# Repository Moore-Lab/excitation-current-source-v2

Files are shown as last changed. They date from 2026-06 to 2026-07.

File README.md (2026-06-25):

# RTD Readout Board

Multi-channel 4-wire RTD readout for a LabJack T7 Pro.

Each RTD gets its own constant-current loop: a **current-regulator diode (CRD, ~220 µA)**
drives a precision **reference resistor R_ref** in series with the RTD. The RTD voltage
**V_RTD** is read on the T7's existing differential pairs; the current-sense voltage
**V_ref** is digitized on-board by **I²C ADS1115** ADCs on the T7's digital lines. Each RTD
is then computed **ratiometrically** as `R_RTD = C · (V_RTD / V_ref)`, where the per-channel
constant `C` is found by one-time **cross-calibration** against a known resistor. This makes
the result independent of the CRD's accuracy and R_ref's absolute value, and fits within the
T7's already-committed 7 analog pairs by moving V_ref onto the I²C bus.

**This build (locked, `docs/board_spec.md` §Resolved inputs):** Pt100 RTDs, T7 range ±0.1 V;
**3 channels** → 3 CRD/R_ref unit cells, **2 ADS1115** (ADDR 0x48/0x49; 4 differential V_ref
reads, 1 spare), 3 RTD 4-wire connectors. The result is **ratiometric across two ADCs**
(T7 + ADS1115), so the dominant design concern is protecting the precision-analog path
(sense + V_ref) and keeping the I²C/digital side off it.

## Where to start
- **Read this first:** `docs/USER_MANUAL.md` — one place to understand the board, see what was
  built, and check the verification evidence (ERC/DRC/SPICE) before fab.
- **Design:** `docs/board_spec.md` (electrical source of truth).
- **Working with Claude Code:** `CLAUDE.md` → `docs/SESSION_KICKOFF.md`.
- **Running multiple sessions in parallel:** `docs/PARALLEL_PLAN.md` + `docs/tasks/`.
- **Process:** `docs/DIRECTORY_MANAGEMENT.md`, `docs/BOARD_DEV_CHECKLIST.md`,
  `docs/TESTING_PLAN.md`.

## Toolchain
- **KiCad 10.0.3** — pinned. The gate scripts auto-discover `kicad-cli` on `PATH`, else at
  the standard Windows install (`C:\Program Files\KiCad\<ver>\bin\kicad-cli.exe`); override
  with `KICAD_CLI=/path/to/kicad-cli`. A KiCad **major** bump can rewrite the `.kicad_*`
  formats — bump the pin in `scripts/lib.sh` deliberately and note it in the log.
- **ngspice** — SPICE engine for Track B's harness (`sim/`).
- **Python + LabJack LJM** — acquisition library in `host/` (Track C). *Not* used by the gate
  scripts, which are POSIX `sh` (run under Git Bash on Windows or natively on Linux/macOS).

## Validation gates
The cheap, machine-checkable gates run from one entry point. It **degrades gracefully**: with
no KiCad design files yet (before the schematic/PCB land) it reports "nothing to check" and
exits 0, so every track and the integration step run it identically.

```sh
sh scripts/run_gates            # ERC + DRC -> reports/{erc,drc}/, nonzero on any error
sh scripts/run_gates --tag s007 # stamp reports as erc_s007.json / drc_s007.json
```

| Script | Does | Output |
|---|---|---|
| `scripts/run_gates` | ERC + DRC; the gate every session runs | `reports/{erc,drc}/*.json` |
| `scripts/erc` | ERC only (canonical command) | `reports/erc/erc_<tag>.json` |
| `scripts/drc` | DRC only (refills zones; never saves the board) | `reports/drc/drc_<tag>.json` |
| `scripts/export_bom` | BOM incl. **Tempco** field (R_ref stability) | `reports/bom/bom_<tag>.csv` |
| `scripts/export_netlist` | Schematic netlist for the SPICE harness | `sim/netlists/rtd-readout.net` |
| `scripts/fab_drop` | Gerbers + drill + pos + STEP + BOM | `fab/**` (gitignored) |
| `scripts/lib.sh` | Shared helpers (sourced, not run) | — |

`reports/**` is generated but **committed** (cheap, diffs well, gives the log something to
cite); regenerate it from these scripts, never hand-edit. Default tag is `latest` (overwrites
for clean diffs); pass `--tag sNNN` to keep a session-stamped copy.

### Optional: enforce gates on commit
```sh
sh scripts/install_hooks   # installs a pre-commit hook that runs scripts/run_gates
```
Opt-in (not installed automatically, so it never surprises a parallel-track worktree). It's a
no-op until the schematic/PCB exist. Remove it with `rm "$(git rev-parse --git-path hooks)/pre-commit"`.

## Cutting a fab drop
Only at a reviewed, **DRC-clean, tagged** rev — `fab/` is gitignored; capture the drop with a
git tag, never leave it in-tree (`docs/DIRECTORY_MANAGEMENT.md`).

```sh
sh scripts/run_gates && git tag rev-A     # gate, then tag the reviewed state
sh scripts/fab_drop                       # gerbers/drill/pos/step/bom -> fab/
git tag fab-rev-A                          # capture the manufacturing drop
```

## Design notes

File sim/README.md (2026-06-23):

# sim/ — SPICE verification harness (Track B)

Headless ngspice proof that the RTD-readout circuit is correct and a quantified
accuracy/noise budget, built on a **modeled** circuit before the board exists.
Implements TESTING_PLAN Part 1. Pt100, 3 channels (`docs/board_spec.md`).

## Layout

```
sim/
├── models/        shared, reused by every deck
│   ├── params.inc   design nominals (CRD, R_ref, gains, Pt100 sweep window)
│   ├── crd.inc      current-regulator diode: I_src || finite Z_dyn, scalable
│   ├── meas.inc     the two ADCs as ideal differential gain blocks (T7, ADS1115)
│   ├── knobs.inc    sweep/perturbation variables carried as node voltages
│   └── channel.inc  one unit cell (CRD + R_ref + RTD + both ADC reads)
├── netlists/      one deck per TESTING_PLAN Part-1 test (test1..test7)
└── scripts/
    ├── spice_io.py  ngspice locator, wrdata loader, report writer, constants
    └── run_all.py   single entry: run decks -> analyse -> plots + reports
```

## Run it

```bash
# from the repo root
python sim/scripts/run_all.py            # run all decks, analyse, write reports
python sim/scripts/run_all.py --no-run   # re-analyse existing data only
```

Outputs (committed): one report per test in `reports/sim/*.md` and plots in
`reports/sim/plots/`. Intermediate `reports/sim/{data,logs}/` are regenerable and
gitignored. Exit code is non-zero if any test FAILs.

## ngspice

Needs the **console/batch** build (`ngspice_con` / `ngspice -b`). The harness
auto-detects it via, in order: `$NGSPICE_BIN`, a conda env named `spice`, then
`PATH`. Provision once with conda-forge (portable, no system install):

```bash
conda create -y -n spice -c conda-forge ngspice      # ships ngspice_con.exe
```

Pinned/validated: **ngspice-41**. KiCad bundles only `ngspice.dll` (no CLI), so a
standalone batch binary is required.

## What each test proves (all PASS on the modeled circuit)

| Deck | Proves | Headline result |
|---|---|---|
| test1 | CRD stays in compliance over the Pt100 sweep at the low rail | min V_CRD 4.26 V ≫ V_L 1.05 V |
| test2 | cross-cal recovers R; invariant to ±10 % CRD / R_ref | error ~7e-9 (numerical floor) |
| test3 | MC accuracy → °C, dominated by R_ref + relative gain tempco | σ ≈ 0.038 °C @ 10 ppm/°C, ΔT 10 °C |
| test4 | worst-case V_ref under ADS1115 range | 221 mV = 86 % FS, 14.8 bits |
| test5 | sense RC settles < ½ LSB within mux dwell | 1.0 ms < 5 ms |
| test6 | ratio noise below target **iff** ADC noise small enough; CRD risk bounded | 13 m°C @ assumed 1 µV T7 — **needs T7 ≤ 1.64 µV RMS**; CRD bound 2.9 nA/√Hz |
| test7 | shared-return crosstalk via finite ADC CMRR (∝ R_gnd) | 1.6 µ°C at 0.1 Ω, max R_gnd ≈ 1.3 kΩ |

Bench-measurable assumptions (T7/ADS noise, mux dwell, targets) are named
constants at the top of `run_all.py`; drop in real datasheet/bench numbers there.

## Architecture notes worth knowing

- **Knobs as node voltages.** `dt, tcref, tcgr, off, kc, kref, rrtd` are 0-impedance
  voltage sources; behavioral models read them as `v(knob)`. This lets every deck
  sweep/perturb headlessly with `alter` (no re-parse) and is why the RTD is swept
  with a plain `.dc Vrrtd ...`.
- **Two ADCs.** `G_T7` and `G_ADS` are independent; the entire *relative* gain
  tempco lives on the T7 path (only the ratio matters). This is the new accuracy
  term vs the old series-chain design.
- **CRD noise cancels** in the ratio under simultaneous sampling (same current in
  V_ref and V_RTD). test6 bounds the i_n that would matter if sampling were *not*
  simultaneous — the one architectural risk to watch on the bench (Stage 8).
- **Crosstalk needs a common-mode path.** Because the victim metric V_RTD/V_ref
  cancels the channel current, shared-return coupling can only appear through the
  ADCs' **finite CMRR** (`cmrr` param in `meas.inc`, default infinite). test7 drives
  it with the aggressor's current spread and reports coupling ∝ R_gnd — small, but
  measured, not zero.

## Wave-3 hook — re-point at the exported KiCad netlist

Today the topology is modeled in `models/channel.inc`. When Track E's schematic
exists, Wave 3 exports `sim/netlists/rtd-readout.net` and the decks can read the
**real** netlist instead of the model. The analysis layer (`run_all.py`) is
topology-agnostic — it only depends on this **node/knob contract**, so keep these
names in the export (or add a thin alias `.include`):

- nodes: `rail`, `top` (R_ref top / V_ref+), `mid` (R_ref bottom = V_ref− = RTD top),
  measurement outputs `nref` (ADS read) and `nrtd` (T7 read);
- knob sources from `knobs.inc` still present (`dt, tcref, tcgr, off, kc, kref, rrtd`);
- the CRD modeled by `crd.inc` and the ADC reads by `meas.inc` (the real board
  digitizes off-deck, so these gain blocks stay as the measurement model).

Concretely: replace the `.include sim/models/channel.inc` line in each deck with
`.include sim/netlists/rtd-readout.net` once it presents the same nodes, re-run
`run_all.py`, and the same pass/fail criteria apply unchanged.

> **Coordination (Track D).** The export must be a **SPICE** netlist, not the KiCad
> s-expression netlist. Track D's `export_netlist` currently emits the s-expr form;
> Wave-3 integration needs `kicad-cli sch export netlist --format spice` (a separate
> `.net`) for the decks to `.include` it. Flagged so D/integration produce the SPICE
> flavor — Track B does not own that export step.

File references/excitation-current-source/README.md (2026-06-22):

# REF200 Multi-Channel 4-Wire RTD Readout Board

A multi-channel, 4-wire RTD readout board: per-RTD **REF200** current sources feeding a
**LabJack T7 Pro** ADC, designed in **KiCad**. Each RTD sits in its own loop near ground
and is measured **ratiometrically** against a precision reference resistor, so the current
source's absolute accuracy and drift drop out of the result:

```
R_RTD = R_ref · (V_RTD / V_ref)
```

**Resolved configuration:** Pt100, 3 channels, 100 µA/channel, REF200 Mode B (2 sources/chip,
2 chips), R_ref = 100 Ω (0.01 %, ≤10 ppm/°C), full-differential 4-wire, T7 ±0.1 V range.
The electrical source of truth is [docs/board_spec.md](docs/board_spec.md).

---

## Repository layout

`hardware/` KiCad project (source) · `libraries/` project-local symbols/footprints/3D ·
`sim/` SPICE decks & scripts · `test/` bench procedures & measured data · `scripts/`
automation (this track) · `reports/` generated ERC/DRC/BOM/sim (committed) · `fab/`
manufacturing outputs (generated, gitignored, tagged per release) · `docs/` the canonical
process and spec documents.

Full rules for what is source vs generated: [docs/DIRECTORY_MANAGEMENT.md](docs/DIRECTORY_MANAGEMENT.md).

## Toolchain

| Tool | Pinned version | Notes |
|---|---|---|
| KiCad | **10.0.3** | On Windows, `kicad-cli` is **not on PATH** — it lives at `C:\Program Files\KiCad\10.0\bin\kicad-cli.exe`. The scripts auto-detect it (see below). |
| Python | 3.12.x | For SPICE analysis / plotting (Track B). |
| ngspice | (standalone) | Not yet installed on the dev box — only KiCad's bundled `ngspice.dll`. Track B's `ngspice -b` flow needs the standalone CLI. |

The automation scripts are POSIX shell. On Windows run them from **Git Bash** (bundled with
[Git for Windows](https://git-scm.com/download/win)); on Linux/macOS any shell works.

`kicad-cli` is located in this order: `$KICAD_CLI` env var → `kicad-cli` on `PATH` → known
Windows install dirs. If KiCad lives somewhere unusual, set `KICAD_CLI=/path/to/kicad-cli`.

## Running the validation gates

One command runs ERC + DRC, writes JSON reports under `reports/erc|drc/`, and exits nonzero
if any gate finds errors:

```bash
bash scripts/run_gates            # reports tagged "latest"
bash scripts/run_gates s002       # name the reports erc_s002.json / drc_s002.json
```

It **degrades gracefully**: until the schematic/PCB exist it reports the gate as `SKIP` and
exits 0 ("nothing to check"), so it's safe in CI and pre-commit from day one.

Individual wrappers (each takes an optional report tag, each skips cleanly if its input file
is absent):

| Script | What it does | Output |
|---|---|---|
| `scripts/run_gates [tag]` | ERC + DRC, summary, nonzero on any error | `reports/erc/`, `reports/drc/` |
| `scripts/erc.sh [tag]` | Schematic ERC (`--severity-error`) | `reports/erc/erc_<tag>.json` |
| `scripts/drc.sh [tag]` | PCB DRC (`--severity-error`) | `reports/drc/drc_<tag>.json` |
| `scripts/bom.sh [tag]` | BOM CSV for review vs board_spec §7 | `reports/bom/bom_<tag>.csv` |
| `scripts/netlist.sh` | Schematic netlist for SPICE/cross-checks | `sim/netlists/ref200-rtd.net` (override `NETLIST_OUT`) |
| `scripts/fab.sh [tag]` | Manufacturing drop (see below) | `fab/` |

Reports are committed for traceability; cite them in the session log (e.g. *"DRC clean —
reports/drc/drc_s007.json"*). Never hand-edit a report — regenerate it.

## Producing a fab drop

`fab/` is **generated and gitignored**. Cut it only at a reviewed, DRC-clean, **tagged**
revision so the exact source is recoverable:

```bash
git tag rev-A                 # tag the reviewed state first
bash scripts/fab.sh rev-A     # exports gerbers + drill + pos + STEP into fab/
git tag fab-rev-A             # tag the drop itself
```

`scripts/fab.sh` refuses to run unless DRC is clean (override: `ALLOW_DIRTY_FAB=1`) and warns
if HEAD isn't tagged (override: `ALLOW_UNTAGGED_FAB=1`).

## Enforcing gates on commit (optional)

An opt-in pre-commit hook blocks commits whose gates fail:

```bash
git config core.hooksPath scripts/hooks    # enable
git config --unset core.hooksPath          # disable
git commit --no-verify                     # bypass once (log why)
```

It's a no-op until the schematic/PCB exist, so it's safe to enable now.

## Process & parallel development

- Start/end-of-session procedure: [docs/SESSION_KICKOFF.md](docs/SESSION_KICKOFF.md)
- Running record / "where we left off": [docs/SESSION_LOG.md](docs/SESSION_LOG.md)
- Engineering gate list: [docs/BOARD_DEV_CHECKLIST.md](docs/BOARD_DEV_CHECKLIST.md)
- Verification plan (SPICE + bench): [docs/TESTING_PLAN.md](docs/TESTING_PLAN.md)
- **Running multiple Claude Code sessions at once:** [docs/PARALLEL_PLAN.md](docs/PARALLEL_PLAN.md)

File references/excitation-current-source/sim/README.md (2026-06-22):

# sim/ — SPICE verification harness (Track B)

ngspice test harness + accuracy/noise budget for the REF200 RTD board, built **before**
the board exists against a modeled unit cell. Proves the circuit is correct and quantifies
the accuracy/noise budget per `docs/TESTING_PLAN.md` Part 1.

## Run it

```bash
python sim/scripts/run_all.py                 # active preset (Pt100, 100 µA, R_ref 100 Ω)
python sim/scripts/run_all.py --preset pt1000_100u
python sim/scripts/run_all.py --ngspice /path/to/ngspice
```

`run_all.py` is the single entry point. It (1) regenerates `netlists/_generated_params.inc`
from `scripts/config.py`, (2) runs all seven decks headless, (3) parses each, decides
pass/fail, plots, and writes `reports/sim/<test>.md` + `.png`, (4) prints a summary and
exits non-zero on any hard FAIL (CONDITIONAL does not fail). Re-running fully regenerates
`reports/sim/` — never hand-edit those.

### ngspice

Needs a **standalone ngspice CLI** (`ngspice -b`). KiCad ships only `ngspice.dll`, which is
not a CLI. Install one and the runner auto-discovers it (`$NGSPICE`, PATH, then a conda
`ngspice` env):

```bash
conda create -n ngspice -c conda-forge ngspice
```

Python deps: numpy, scipy, matplotlib (already present in the project env).

## Layout

```
sim/
├── models/
│   ├── ref200.lib      # REF200 100 µA section: ideal source ∥ 50 MΩ (no TI model exists)
│   └── README.md       # model strategy, noise handling, where to drop a TI model
├── netlists/
│   ├── _generated_params.inc   # GENERATED from config.py (committed copy = active preset)
│   ├── 01_dc_op.cir            # DC operating point & compliance margin
│   ├── 02_ratiometric.cir      # ratiometric correctness (R_calc = R_ref·V_RTD/V_ref)
│   ├── 03_accuracy_rref.cir    # SPICE sensitivity of recovered R to R_ref deviation
│   ├── 04_compliance_corner.cir# worst-case compliance corner
│   ├── 05_transient_settling.cir# sense RC settling vs mux dwell
│   ├── 06_noise.cir            # .noise of passive/Johnson chain through the filter
│   └── 07_crosstalk.cir        # shared star-ground crosstalk
├── scripts/
│   ├── config.py       # ONE design point (presets + derived); edit here to re-target
│   ├── rtd.py          # Callendar–Van Dusen Pt100/Pt1000 R<->T (maps ΔR -> ΔT in °C)
│   ├── analysis.py     # parse, pass/fail, plots, Monte-Carlo accuracy -> °C
│   ├── report.py       # render a result into the TESTING_PLAN markdown skeleton
│   └── run_all.py      # single headless entry point
└── scratch/            # raw ngspice wrdata (gitignored; runner actually uses a temp dir)
```

The deck/output paths are decoupled from the source tree: the runner stages a **local
temp copy** of the decks/models and runs ngspice there, because rapid `wrdata` file
creation in this OneDrive-synced tree silently drops files. `sim/scratch/` stays empty in
normal operation; the committed `_generated_params.inc` keeps the decks runnable by hand.

## Re-targeting (Pt100 ↔ Pt1000, R_ref, etc.)

Everything keys off `scripts/config.py`. Change `ACTIVE`, or a preset's `r_ref` / `i_exc`
/ `t7_*`, and re-run — decks, params, and reports all follow.

## Wave-3 hook — swap the modeled cell for the real netlist

These decks model the unit cell directly. At fabrication (Track G), KiCad exports the real
netlist to `sim/netlists/ref200-rtd.net`. To re-validate against the as-designed circuit:

1. Export from KiCad: `kicad-cli sch export netlist --format spice -o sim/netlists/ref200-rtd.net hardware/ref200-rtd.kicad_sch`.
2. In each deck, replace the inline unit-cell elements (the `Vrail`/`Xsrc`/`Rref`/`Rrtd`
   block) with `.include netlists/ref200-rtd.net` and an `X` call to the exported subckt,
   keeping the same node names for the sense/ref taps so the `.control` math is unchanged.
3. Re-run `run_all.py`; the pass/fail criteria and reports are identical, now against the
   real netlist. Confirm the numbers still hold (especially compliance and noise).

## Current results (preset `pt100_100u`)

| Test | Verdict | Headline |
|---|---|---|
| 01 DC op / compliance | PASS | min source headroom 4.72 V (≫ 2.5 V) |
| 02 ratiometric | PASS | R_calc error < 1e-9 ppm (exact, I/R_out-independent) |
| 03 accuracy → °C | **CONDITIONAL** | R_ref floor 20 m°C; meets ±0.1 °C only with per-channel offset null + averaging (offset, not R_ref, dominates at 100 µA) |
| 04 compliance corner | PASS | worst-corner headroom 4.72 V |
| 05 sense settling | **CONDITIONAL** | needs per-channel RC (before mux) or smaller C; a shared 0.1 µF needs ~1.7 ms > 1 ms dwell |
| 06 noise | PASS | 216 nV RMS chain ≪ 1.4 µV ADC floor |
| 07 crosstalk | PASS | 10 pV (0.26 µ°C) at R_star 0.05 Ω |

The two CONDITIONALs are design/measurement requirements for downstream tracks, not circuit
failures — see the respective reports for the exact actions (offset nulling + averaging;
per-channel sense RC placement).

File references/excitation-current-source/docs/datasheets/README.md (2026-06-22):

# Datasheets — REF200 RTD board

Index of part datasheets and the **verified parameters** the Track-A libraries were built
from. Where a PDF is committed here it is the authoritative copy; where only a URL is given,
the vendor blocks automated download (TI/Vishay/Mouser anti-bot) or the file is large — grab
it manually if you need the full document. Parameters below are what the symbol/footprint
fields encode, so the schematic (Track E) can be reviewed without opening each PDF.

| Part | Role | Datasheet | Local PDF |
|---|---|---|---|
| REF200AU | Dual 100 µA current source (excitation) | https://www.ti.com/lit/ds/symlink/ref200.pdf | — (TI interstitial blocks curl) |
| Vishay VSMP1206 (100 Ω) | Precision reference resistor R_ref | https://www.vishaypg.com/docs/63001/vsmp.pdf | — (vendor anti-bot) |
| TI LP2985-5.0 | Low-noise 5.0 V LDO | https://www.ti.com/lit/ds/symlink/lp2985.pdf | — (10 MB; URL only) |
| 1N4148W | Optional reverse-V protection diode | https://www.diodes.com/assets/Datasheets/ds30086.pdf | `1N4148W_diodes.pdf` ✓ |
| Phoenix MKDS 1,5/x-5,08 | Screw terminals (RTD 4-wire, power) | https://www.phoenixcontact.com (search "MKDS 1,5/4-5,08") | — |

## Verified parameters (encoded in the library fields)

### REF200AU — Texas Instruments — SOIC-8 (Package_SO: SOIC-8_3.9x4.9mm_P1.27mm, JEDEC MS-012AA)
Pin map (from `board_spec.md` §2, cross-checked against KiCad's official `Reference_Current:REF200AU`):

| Pin | Name | Pin | Name |
|----:|---|----:|---|
| 1 | I1 Low (source 1 out) | 5 | Mirror Input (unused) |
| 2 | I2 Low (source 2 out) | 6 | Substrate → GND |
| 3 | Mirror Common (unused) | 7 | I2 High (source 2 supply) |
| 4 | Mirror Output (unused) | 8 | I1 High (source 1 supply) |

Used in **Mode B** (independent sources, 100 µA each): pin 8→+5 V, pin 1→R_ref_A→RTD_A;
pin 7→+5 V, pin 2→R_ref_B→RTD_B. Substrate (6) to GND. Mirror (3/4/5) left open (NC).

### Vishay VSMP1206 — 100 Ω reference resistor — R_1206_3216Metric
- **Selected MPN:** `Y1625100R000Q9R` (in-stock at RS/Mouser): 100 Ω, **±0.02 %**, **±0.2 ppm/°C**, 0.33 W, Z-Foil.
- Spec target is 0.01 % / ≤10 ppm/°C. Tempco (0.2 ppm/°C) beats the requirement ~50×.
  The ±0.01 % tolerance grade of the **same VSMP1206 series is a drop-in** (identical 1206
  footprint) if untrimmed absolute tolerance matters; in this **ratiometric** design R_ref is
  measured per board, so tempco/drift — not initial tolerance — dominates. See trackA log.

### TI LP2985-5.0 — low-noise LDO — SOT-23-5
- MPN `LP2985IM5X-5.0/NOPB`. 150 mA, fixed 5.0 V, low-noise (BYP pin). Pinout (SOT-23-5):
  1 VIN, 2 GND, 3 EN (ON/OFF), 4 BYP, 5 VOUT. Board draws ~0.5 mA (4×100 µA + housekeeping),
  far inside 150 mA. The 3.3 V grade (LP2985-3.3) is a drop-in if a 3.3 V rail is preferred.
- **The LDO is the least-critical part** (spec §4: ratiometric rejects rail noise). Treat the
  exact LDO as a power-stage design choice; LT3045/ADP7142 are lower-noise alternatives but
  need their own footprint/pinout.

### 1N4148W — Diodes Inc — SOD-123
- MPN `1N4148W-7-F`. Optional, one per source, anti-parallel for reverse-V clamp (REF200
  datasheet Fig. 17a). Footprint pad 1 = cathode (matches symbol pin 1 = K).

### Phoenix Contact MKDS 1,5/x-5,08 — screw terminals
- `MKDS 1,5/4-5,08` (1×04, RTD: Force+/Sense+/Sense−/Force−) and `MKDS 1,5/2-5,08`
  (1×02, +5 V_IN/GND). 5.08 mm pitch, THT, horizontal wire entry.

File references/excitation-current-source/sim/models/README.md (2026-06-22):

# SPICE model strategy

Track-B model layer for the REF200 RTD board. Source of truth for *what the decks
believe the hardware is*. Re-point at the real KiCad-exported netlist at Wave 3
(see `sim/README.md` and `docs/sessions/trackB.md`).

## REF200 — `ref200.lib`

**No vendor model exists.** TI's REF200 product page ships a datasheet but **no
SPICE/PSpice model** (checked 2026-06-19). If TI ever publishes one, drop it here and
have `02_ratiometric` / `06_noise` `.include` it instead of `ref200.lib` — the rest of
the harness is unaffected because every deck references the section only through the
`ref200_src` subckt name.

Until then, each 100 µA section is modelled per `TESTING_PLAN.md`:

| Element | Value | Justification |
|---|---|---|
| Ideal DC current source | `iset` (100 µA resolved) | the section's defining behaviour |
| Parallel output resistance `rout` | 50 MΩ | datasheet output impedance 20–100 MΩ; 50 MΩ nominal |

Mode A (200 µA) = two sections in parallel → just instantiate `ref200_src` twice
across the same nodes, or set `iset=200u` and `rout=25meg`.

The finite `rout` is deliberately included so the ratiometric decks can *prove* the
result is independent of it: the same series current flows through `R_ref` and the
RTD regardless of how much `rout` shunts, so the ratio `V_RTD/V_ref` is exact.

## RTD — swept resistor

The RTD is a plain resistor swept across its operating band. Resistance ↔ temperature
uses Callendar–Van Dusen (IEC 60751) in `sim/scripts/rtd.py`, **not** a SPICE element,
because the decks only need the resistance and the *temperature* mapping belongs in
the analysis (it converts a resistance error into an equivalent °C error).

- Pt100: ~80.3 Ω (−50 °C) … 157.3 Ω (+150 °C)
- Pt1000: ~803 Ω … 1573 Ω

## R_ref — parameter

`r_ref` is a parameter (`config.py`), 100 Ω resolved. Tolerance (0.01 %) and tempco
(10 ppm/°C) are applied in the Monte-Carlo accuracy analysis, not baked into the deck,
so one deck serves nominal, corner, and statistical runs.

## Noise

An ideal current source is **noiseless** in ngspice `.noise`, so `06_noise.cir`
computes only what ngspice models natively and correctly: the **Johnson noise of
`R_ref`, the RTD, and the sense RC-filter resistors, band-limited by the filter**,
output-referred to the ADC differential input.

The **REF200 excitation current noise** is then added analytically by
`analysis.py` from the datasheet figures, because it is not a SPICE-native element:

- White: **20 pA/√Hz** → ×`R` gives the excitation voltage-noise density.
- Flicker (0.1–10 Hz): **1 nA p-p** → ≈ `1n/6.6` ≈ 0.15 nA rms over the decade band.

Both are tiny (20 pA × 100 Ω = 2 nV/√Hz white) and the slow/flicker part cancels
ratiometrically anyway, but they are carried explicitly so the budget is complete and
honest rather than silently dropping the excitation term.

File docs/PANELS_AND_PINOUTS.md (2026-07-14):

# rev-G — enclosure, panels, and cable pinouts

Board: **100.0 × 159.5 mm**, slides into a **Hammond 1455N1601** (103×53×160, clear anodized,
DigiKey HM979-ND) on the lowest card slot. No mounting holes — the slots carry the board;
**2.5 mm component/outer-copper keepouts along both 159.5 mm edges** (slot engagement) are
respected by the layout. End panels (103×53×1.5 Al) are machined per the DXFs in
`reports/review/panel-sensor.dxf` / `panel-daq.dxf` — **verify the H0=9.54 mm board-top
datum against the physical enclosure before cutting** (Hammond publishes no slot tolerances).

## Sensor end (board x=0): 4× Phoenix PT 1,5/5-3,5-H (push-in, 26–16 AWG, use ferrules)

Per RTD block, pins top→bottom as seen on the panel (pin 1 at each block's north end):

| Pin | Function |
|---|---|
| 1 | Force + (MID) |
| 2 | Sense + |
| 3 | Sense − |
| 4 | Force − (GND return) |
| 5 | **Cable shield** (AGND; land the cryostat STP shield here, one end only) |

Blocks are PT **push-in** (not screw): ferruled wires insert directly through the panel
cutout; the release actuator is on top — remove the end panel (4 screws) for full access.
RTD1=J1, RTD2=J2, RTD3=J3, spare=J7 (top→bottom on the panel).

## DAQ end (board x=159.5)

**RJ45 (J4, Amphenol RJHSE-5380, shielded)** → LabJack T7 AIN via CAT6a S/FTP patch cable
(cut one end, land in the T7/CB37 screw terminals). T568B mapping — each channel rides one
physical twisted pair:

| Channel | RJ45 pins | T568B pair color |
|---|---|---|
| CH1 (T7±) | 1 / 2 | orange (wht-org / org) |
| CH2 | 3 / 6 | green (wht-grn / grn) |
| CH3 | 4 / 5 | blue (blu / wht-blu) |
| CH4 | 7 / 8 | brown (wht-brn / brn) |

Cable **shield → AGND at the board end only** (via the jack shield tails); leave the
pigtail-end shield unterminated. The jack's EMI fingers bond the enclosure panel at the
cutout — this is the **single chassis-ground point** by design.

**I²C/power pigtail (J5, Molex PicoBlade 53048-0410; mate = pre-made pigtail
2181120404, 425 mm, or 2181120402, 225 mm — NO crimping)** → cut the flying-lead end to
length and land in the T7 screw terminals. ⚠ **Pin numbers are deliberately reversed**
(rev-G routing). Identify wire 1 by the pin-1 mark on the pigtail housing / the header's
pin-1 pad (square), then:

| PicoBlade pin | Net | T7 terminal |
|---|---|---|
| 1 | SCL | FIO (I²C SCL) |
| 2 | SDA | FIO (I²C SDA) |
| 3 | GND | GND |
| 4 | VS | VS |

This cable carries the **common-mode reference and the ADS1115 supply — it must be
connected whenever measuring** (the analog cable has no ground conductor).

**Power (J6, Phoenix PT 1,5/2-3,5-H):** pin 1 = +5 V, pin 2 = GND (bench supply).

## Bench-probing note

The 2×5 header is gone; probe the filtered nets at the T7-end pigtail/breakout. The
unfiltered `CHn_SENSE±` test points (TP1–TP12) are unchanged on the board.

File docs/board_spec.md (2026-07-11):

# board_spec.md — RTD Readout Board

Electrical design source of truth. Every component value and layout choice traces back
here. The companion process docs (`PARALLEL_PLAN.md`, the track briefs, the checklist,
the testing plan) implement what this file specifies.

## What the board does

Reads up to 7 four-wire RTDs on an existing LabJack T7 Pro whose 7 differential analog
pairs are **all already committed to the RTD voltage measurements**. Each RTD gets its own
constant-current loop (so it sits near ground — this kills the common-mode/position-
dependent noise that a series chain produced), and the per-channel excitation current is
measured **live** so the source's accuracy and drift never enter the result.

The trick that makes it fit with zero spare analog channels: the current-sense voltage is
digitized on the board by I²C ADC(s) on the T7's digital lines, not on an analog pair.

## Signal chain, per channel

```
   +V rail (5 V; higher improves CRD regulation if available)
      │
   [ CRD ]            current-regulator diode, ~100 µA (SEMITEC S-101T, SMD), two-terminal
      │  I (same current through everything below)
  TOP ●───────────────► ADS1115 IN+   ┐ V_ref read differentially on-board, over I²C
   [R_ref]                            │
  MID ●───────────────► ADS1115 IN−   ┘
      │  Force+  (to RTD)
      ▼
   [ RTD 4-wire ]   Sense+ ●─────────► T7 AINx+  ┐ V_RTD on the existing T7 diff pair
                    Sense− ●─────────► T7 AINx−  ┘ (Kelvin, full 4-wire)
      │  Force−
      ▼
   STAR GND
```

## The measurement

The same current `I` flows through `R_ref` and the RTD. V_RTD is measured by the T7;
V_ref is measured by an ADS1115. Because they are on **different ADCs**, the raw ratio
carries the ratio of the two converters' gains:

    V_RTD_meas / V_ref_meas = (G_T7 / G_ADS) · (R_RTD / R_ref)

Fold everything constant into a single per-channel calibration constant **C**:

    R_RTD = C · (V_RTD_meas / V_ref_meas)

Measure C once by substituting a known resistor for the RTD:

    C = R_known · (V_ref_meas / V_RTD_meas)│_known

C absorbs `R_ref`'s value, the gain ratio, and any fixed offsets. Consequences:

- The CRD's ±10 % tolerance, tempco, and channel-to-channel spread are **irrelevant** —
  the current is measured live and cancels.
- `R_ref`'s **absolute value is irrelevant** (absorbed into C). Only its **stability**
  (tempco, low noise) matters.
- The accuracy limiters after cross-cal are: (1) the `R_known` used at calibration time
  (a 0.01 % part, used once), (2) `R_ref` tempco between recals, and (3) the **relative
  gain tempco of the two ADCs** between recals. Keep both converters thermally stable and
  recalibrate periodically.

Sensitivity, as a feel for the budget (Pt100): a fractional error `ΔI/I`-equivalent in the
ratio shows up as ≈ `260 · (error)` °C. So ~100 ppm of combined drift ≈ 0.026 °C.

## Components

### Current source — CRD (current-regulator diode)
- **SEMITEC S-101T, SMD flat 2-lead**, ~0.10 mA typical, band 0.05–0.21 mA guaranteed
  (−50 %/+110 %), Vk 0.5 V max, 100 V, 500 mW.
  *rev-F (2026-07-11):* current lowered ~2.4× (from the rev-E 0.24 mA J500) because the
  Pt100s sit **in vacuum in a cryostat (down to ~100 K)** where self-heating cannot
  convect away — at 100 µA the sensor dissipates ~0.3–1.6 µW (~6× less). The S-101T's
  huge band and up-to-+2.1 %/°C Ip tempco are cancelled by the ratiometric readout —
  stability burden sits on R_ref and the ADC gain ratio, not the CRD.
  Anode → rail, cathode → R_ref.
- Exact current is unimportant (measured live). It must only be **stable over one scan**
  and quiet. Compliance: needs a few volts across it to regulate; on a 5 V rail with
  ~0.25 V of load drop it sees ~4.7 V — verify against the chosen CRD's limiting voltage
  `VL`. A higher rail (e.g. 12 V) raises its dynamic impedance; CRD dissipation is trivial
  (~mW).

### Reference resistor R_ref
- Stable, low-tempco (≤10 ppm/°C), low-noise. **Absolute tolerance does not matter**
  (cross-cal absorbs it) — do not pay for 0.01 % here; pay for tempco and stability.
- **Size R_ref to the ADS1115 input range, not to the RTD.** Target V_ref near full-scale
  of the chosen PGA range, with margin for the CRD's +10 % spread so it never clips.
  Default (rev-F, sized for the S-101T band): **R_ref = 1.00 kΩ, ±0.05 %, ±2 ppm/°C**
  (Vishay TNPU12061K00AWEN00 bulk-thin-film) → V_ref ≈ 100 mV nominal, ≤ 210 mV (82 % FS)
  at the 0.21 mA band max — never clips the ADS1115 **±0.256 V** range (7.8125 µV/LSB).
  At ±2 ppm/°C the reference is deliberately **no longer the drift limiter** (ADC gain
  tempco and offset drift are); this is the rev-F stability-first policy: precision parts
  everywhere in the measurement path (2 ppm R_ref, 0.1 %/25 ppm thin-film filter R's,
  C0G/NP0 sense capacitors), ordinary grades for rails and digital.

### Current-sense ADC — ADS1115 (I²C)
- 16-bit, programmable-gain, I²C, four selectable addresses (0x48–0x4B via the ADDR pin).
  Two true differential inputs per chip (AIN0-1, AIN2-3). **7 channels → 4 chips → 8
  differential V_ref reads** on a single 2-wire bus.
- Read V_ref **differentially** at the R_ref pads. The V_ref common-mode (≈ V_RTD + V_ref/2,
  a few hundred mV) is well within the ADS1115's GND–VDD input range.
- Supply 3.3–5 V (e.g. from the T7's VS); add per-chip decoupling and bus pull-ups
  (4.7 kΩ typical; 2.2 kΩ if the bus is long/fast). Average several conversions per read to
  beat the LSB noise on the small signal.

### RTD voltage — existing T7 Pro pairs
- V_RTD on each RTD's existing differential pair, Kelvin-sensed at the RTD. Range: **±0.1 V**
  for Pt100 (≈3–16 mV at ~100 µA, 100 K floor), **±1 V** for Pt1000 (≈80–157 mV at 100 µA). Set the resolution
  index high and give each channel adequate mux settling.

## Board as the hub / interfaces

The board is the measurement hub. It takes the RTDs in, forms each current loop with a CRD
and R_ref, digitizes V_ref locally on the ADS1115s, and routes outward:
- **RTD connectors:** 4-wire (Force+, Force−, Sense+, Sense−) per RTD.
- **To the T7 analog (CB37):** the 7 Sense± pairs (V_RTD). Only these analog lines leave the
  board; V_ref never travels as analog.
- **To the T7 digital (I²C):** SDA, SCL, VS, GND.
- **Power in:** to the rail/LDO.

## Layout-critical points (full list in BOARD_DEV_CHECKLIST.md)
- **Star ground:** all RTD Force− returns and the analog ground meet at one point. Shared
  return impedance between channels is the crosstalk path.
- **RTD at the bottom of each loop** (low common-mode) — the reason the board exists.
- **Mixed-signal discipline (new):** the I²C bus and ADS1115 digital side are switching
  digital traffic next to µV-level analog. Partition analog/digital grounds with a single-
  point tie, keep I²C away from the R_ref taps and the sense pairs, decouple every ADS1115.
- Each ADS1115 sits **next to its two R_ref pairs**; route V_ref as a tight differential
  pair with the shortest possible path.
- 4-wire Kelvin preserved to each RTD; light sense-line RC filter at the T7 input.
- Test points on: each TOP node, each MID/Sense+ node, the rail, GND, SDA, SCL.

## Resolved inputs (locked 2026-06-22, Session 002 — Lucas; channel count revised
## 2026-07-09, Session 008 — Lucas: use the spare ADS1115 pair → 4 channels)
1. **RTD type = Pt100.** → T7 range **±0.1 V** (≈3–16 mV at ~100 µA, 100 K floor). Set a high resolution
   index and adequate mux settling per channel. (Does not affect R_ref sizing, which keys off
   the ADS range, or the CRD.)
2. **Channel count = 4** of the 7 T7 differential pairs are RTDs (was 3; the second ADS1115's
   AIN2/AIN3 differential pair was spare, so CH4 costs no new ADC). This fixes the repeated
   hardware:
   - **4 CRD/R_ref unit cells** (4× CRD SEMITEC S-101T, 4× R_ref 1.00 kΩ on the ADS ±0.256 V
     range).
   - **2 ADS1115** (1 chip per 2 channels → ceil(4/2) = 2): 4 differential V_ref reads, **4
     used, 0 spare**. Strap ADDR for **0x48 and 0x49**. U1 reads CH1/CH2; U2 reads CH3/CH4.
   - **4 RTD 4-wire connectors**; 4 of the 7 Sense± pairs go to the T7 analog (CB37). The
     other 3 T7 pairs remain free for non-RTD use.
   - **T7 analog connector = 2×5 header** (was 2×4): pins 1–6 = CH1–CH3 Sense± pairs,
     pins 7/8 = AGND (kept per the analog-reference intent), pins 9/10 = CH4 Sense±.

Cross-cal + ratiometric absorb component values, so these set ranges and counts, not
precision. The build is intentionally scalable: adding channels later means more unit cells
and (every 2 channels) another ADS1115 — no architectural change.

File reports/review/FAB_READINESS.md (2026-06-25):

# Fab-Readiness Check — rev-A

Board: `hardware/rtd-readout.kicad_pcb` (frozen at tag `rev-A`). Package: `fab/` (tag `fab-rev-A`).

## Stackup
- **4 copper layers**, signal: `F.Cu`, `In1.Cu`, `In2.Cu`, `B.Cu`.
- Board thickness **1.6 mm**; dielectric layers present in the KiCad stackup.
- Board outline defined on `Edge.Cuts` (exported as `rtd-readout-Edge_Cuts.gm1`).

## Design rules (manufacturable by standard 4-layer fabs)
| Netclass | Track | Via (Ø/drill) | Clearance |
|---|---|---|---|
| Default | 0.25 mm | 0.6 / 0.3 mm | 0.13 mm |
| I2C | 0.25 mm | 0.6 / 0.3 mm | 0.13 mm |
| SENSE | 0.25 mm | 0.6 / 0.3 mm | 0.13 mm |
| POWER | 0.50 mm | 0.8 / 0.4 mm | 0.13 mm |

Board minimums: min track 0.13 mm, min hole 0.2 mm. All within common fab capability
(≈0.1 mm track/space, 0.2 mm drill).

## Gerber/drill package (`fab/`)
- Gerbers: F/B Cu, In1/In2 Cu, F/B Mask, F/B Silkscreen, F/B Paste, F/B Adhesive,
  F/B Courtyard, F/B Fab, Edge_Cuts, Margin, User_* + `.gbrjob`.
- Drill: `rtd-readout.drl`.
- Placement: `pos/rtd-readout-pos.csv` (mm).
- 3D: `rtd-readout.step`.
- BOM: `bom/bom_fab.csv`.

## Gates at this rev
- ERC **0 errors / 0 warnings** (`reports/erc/erc_rev-A.json`).
- DRC **0 violations / 0 unconnected** (`reports/drc/drc_rev-A.json`).
- Schematic parity: 47 non-blocking issues — mechanical footprints without symbols
  (mounting holes / fiducials) + un-synced footprint metadata fields. No net/connectivity
  errors. (Pre-existing in Track F; documented in SESSION_LOG Session 004.)

## Not done here (out of scope / needs hardware)
- **Panelization** — single-board outline only; add at the fab portal if required.
- **Bench verification** (TESTING_PLAN Part 2: cross-cal, noise/position-independence,
  thermal C-drift, CRD-noise) — requires the physical board; Lucas runs on assembly.

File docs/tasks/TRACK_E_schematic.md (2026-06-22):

# TRACK E — Schematic Capture  *(Wave 1 — gated)*

> **Do not start until:** Track A is merged into `integration` (symbols/footprints exist)
> **and** Lucas has resolved RTD type + channel count (`board_spec.md` open inputs). Branch
> off the post-A `integration`.

Claude Code session, **Track E**. Read `CLAUDE.md`, `docs/board_spec.md` (all),
`docs/BOARD_DEV_CHECKLIST.md` (Phase 1), `docs/SESSION_KICKOFF.md`, and your log
`docs/sessions/trackE.md`. Work **only** in your owned paths.

## Owned paths (exclusive write)
`hardware/*.kicad_sch`, `hardware/rtd-readout.kicad_pro` (schematic-side settings)

## Must NOT touch
`hardware/*.kicad_pcb` (Track F), `libraries/` (Track A), `sim/`, `host/`, `test/`,
`scripts/`.

## Goal
Capture the full schematic from `board_spec.md`, ERC-clean, using only project-local
library parts.

## Build (hierarchical sheets)
- **`unit_cell` sheet (×N channels):** CRD (anode→rail, cathode→R_ref) → R_ref → RTD 4-wire
  connector; RTD at the bottom of the loop to GND; Force/Sense as separate nets; Kelvin at
  the RTD. Tap V_ref differentially at the R_ref pads.
- **`ads1115` sheet:** 1 chip per 2 channels; each chip's two differential inputs wired to
  two channels' R_ref taps; **unique ADDR straps (0x48–0x4B)**; per-chip decoupling; one set
  of SDA/SCL pull-ups; supply from T7 VS or a regulated 3.3–5 V.
- **`power` + `connectors` sheets:** rail/LDO + decoupling; RTD connectors; the 7 Sense±
  pairs out to the T7 analog (CB37); SDA/SCL/VS/GND out to the T7 digital. Only V_RTD leaves
  as analog.
- Test points on each TOP node, each Sense+/MID node, rail, GND, SDA, SCL.
- Every symbol fully fielded; power flags; meaningful per-channel net labels.

## Done when
- ERC clean: **0 errors** (warnings fixed or justified in the log).
- BOM exported and cross-checked vs `board_spec.md` (CRD = channels, ADS1115 = ceil(ch/2),
  R_ref = channels, pull-ups/decoupling present).
- Netlist exported to `sim/netlists/rtd-readout.net` for Track B's Wave-3 re-point.
- Committed on `trackE`; log updated.

## Coordination
Branch `trackE` off post-A `integration`. If split: **E1** owns `unit_cell`, **E2** owns
`ads1115`+`power`+`connectors`; one owns the root sheet — coordinate the hand-off. Commit;
integration merges E before F. Log to `docs/sessions/trackE.md`.

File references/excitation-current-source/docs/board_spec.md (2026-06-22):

# Multi-Channel 4-Wire RTD Readout — REF200 + LabJack T7 Pro

Ratiometric, current-source-per-RTD board to replace the series-chain topology. Each
RTD gets its own loop near ground (kills the CMRR / position-dependent noise), and each
channel measures its own excitation against a precision reference resistor so the
REF200's absolute accuracy and drift drop out of the result.

Measurement equation (per channel):

    R_RTD = R_ref · (V_RTD / V_ref)

Both voltages carry the **same** current, so the current value never enters the answer.

---

## 1. Unit cell

One REF200 current-source section, one reference resistor, one RTD. RTD sits at the
bottom of the stack (lowest common-mode → smallest CMRR error).

```
        +V rail (LDO, +5 V)
            │
        ┌───┴────┐
        │ REF200 │   source "High" terminal(s)
        │ source │
        └───┬────┘   source "Low" terminal(s)
            │  ← I (200 µA or 100 µA), set by strap
        TOP ●─────────────► AIN (V_ref +)        ── measure V_ref across R_ref
            │
          [R_ref]   precision, 0.01%, ≤10 ppm/°C
            │
        MID ●─────────────► AIN (V_ref − / shared with RTD Sense+)
            │  Force+  (long lead to RTD)
            ▼
        ┌───────┐
        │  RTD  │   Sense+ ●──────► AIN (V_RTD +)   ── Kelvin, no force-lead drop
        │ 4-wire│   Sense− ●──────► AIN (V_RTD −)
        └───┬───┘
            │  Force−  (long lead)
            ▼
          STAR GND
```

- **Reference resistor on top, RTD on the bottom.** Keeps the RTD differential
  common-mode at ≈ V_RTD/2 (tens of mV), so the T7's finite CMRR contributes
  negligibly — the failure mode of the old series chain.
- **R_ref is on-board (2-wire is fine)** — short traces, known value. The RTD keeps
  full 4-wire Kelvin.
- **Substrate (pin 6) → GND** (most negative node) for rated DC performance. Leave the
  unused current-mirror section (pins 3/4/5) open.

---

## 2. REF200 pinout & strap (SOIC-8, top view)

| Pin | Name | Function |
|----:|---|---|
| 1 | I1 Low | Source 1, low (output) terminal  |
| 2 | I2 Low | Source 2, low (output) terminal  |
| 3 | Mirror Common  | unused |
| 4 | Mirror Output  | unused |
| 5 | Mirror Input | unused |
| 6 | Substrate | tie to GND (most negative) |
| 7 | I2 High | Source 2, high (supply) terminal |
| 8 | I1 High | Source 1, high (supply) terminal |

Current enters "High", exits "Low" into the load. One chip = **two 100 µA sections**.

**Mode A — 200 µA, one channel/chip** (parallel both sources, per datasheet Fig. 19a):
- Pin 8 + Pin 7 → +V rail
- Pin 1 + Pin 2 → TOP node (into R_ref)

**Mode B — 100 µA, two channels/chip** (sources independent):
- Channel A: Pin 8 → +V rail, Pin 1 → R_ref_A → RTD_A
- Channel B: Pin 7 → +V rail, Pin 2 → R_ref_B → RTD_B

Optional reverse-V protection (only matters on fault/hot-plug): one 1N4148 in parallel
with each source per datasheet Fig. 17a; clamps reverse to ~0.7 V. Not needed in normal
operation since the Low node always sits below the High node.

---

## 3. Current & reference-resistor selection

| RTD | Current | Mode | V_RTD (−50…+150 °C) | R_ref  | V_ref  | T7 range | Chips |
|---|---|---|---|---|---|---|---|
| Pt100  | 200 µA  | A | 16 – 31 mV | 100 Ω  | 20 mV  | ±0.1 V | 1/ch  |
| Pt1000 | 100 µA  | B | 80 – 157 mV | 1 kΩ | 100 mV | ±1 V | ½/ch  |
| Pt1000 | 200 µA  | A | 160 – 314 mV | 1 kΩ | 200 mV | ±1 V | 1/ch  |

Rule of thumb: **R_ref = RTD nominal (R0)** → ratio ≈ 1, balanced resolution on both
measurements.

- **Pt100 → run at 200 µA.** At 100 µA the 10 mV signal fights the T7 resolution floor.
- **Pt1000 → run at 100 µA.** Plenty of signal, and you get **two channels per chip**,
  halving chip count and cost.

Reference resistor is now your dominant accuracy/drift term, so spend here (this is the
budget the old plan wasted on a buck regulator): 0.01 %, ≤10 ppm/°C thin-film or foil.
Self-heating is negligible (4 nW in a 100 Ω at 200 µA), so any package is fine — but keep
it out of airflow/thermal gradients and away from anything that dissipates heat.

---

## 4. Power

- **Single +5 V rail from a low-noise LDO** (e.g. LT3045 if you want it quiet; honestly
  any clean LDO works because ratiometric rejects rail-induced current variation). Feed
  it from whatever you already have. **No DC-DC buck** — it only adds switching trash next
  to a µV-level measurement.
- Compliance check: source sees Vrail − (V_ref + V_RTD) ≈ 5 V − ~0.05–0.3 V ≈ 4.7–4.95 V,
  well above the 2.5 V minimum. 3.3 V would also work.
- REF200 source noise is a non-issue here: ~1 nA p-p (0.1–10 Hz) → ~140 nV p-p across a
  100 Ω, and the slow part cancels ratiometrically anyway. The measurement noise floor
  stays set by the T7 ADC and Johnson noise, not the excitation.

---

## 5. T7 AIN budget — the channel-count decision

The T7 has **14 AIN → 7 differential pairs**. How many RTDs you can read depends on the
measurement mode:

| Mode | Per channel | Kelvin? | Max channels | When to use |
|---|---|---|---|---|
| **Full differential** | V_RTD diff pair + V_ref diff pair = 4 AIN | full 4-wire | **3** | ≤3 RTDs, best noise |
| **Single-ended subtract** | TOP_Rref, Sense+, Sense− as 3 SE reads | full 4-wire | **4** | 4 RTDs; CM is sub-volt so SE is fine |
| **Calibrated current** | V_RTD diff pair only = 2 AIN | full 4-wire | **7** | many RTDs; drop per-channel V_ref |

- **Full differential** is cleanest but caps at 3 channels.
- **Single-ended subtract**: read TOP-of-R_ref, Sense+, and Sense− each vs GND and
  subtract in software. Because every node is < 1 V, SE accuracy is fine and you keep
  Kelvin (you're still reading the actual sense leads). 3 AIN/channel → 4 channels.
- **Calibrated current**: measure each channel's actual current once with a good DMM,
  store it, and trust the REF200's 25 ppm/°C drift + long-term stability. Drops V_ref,
  so 2 AIN/channel → up to 7. Trade ratiometric robustness for density. Reasonable if the
  board's temperature is stable to a few °C.

If you need more than 7, the current sources are independent — add a second T7, or
multiplex sense pairs through an external low-leakage mux (watch settling).

**Read raw voltages and compute R in software** — don't use the AIN_EF RTD feature here,
since that assumes the single internal source. Just grab V_RTD and V_ref and apply the
ratio.

---

## 6. Layout & wiring

- **Star ground:** all RTD Force− returns, LDO ground, and T7 GND meet at one point.
  Independent loops near ground are the whole reason the noise goes away — don't let them
  share a long return trace.
- **Force vs Sense:** route as separate pairs all the way to the RTD; Kelvin connection
  made at the RTD terminals. Sense leads carry only the **T7 input bias current ≈ 20 nA**
  (datasheet — *not* pA-level as earlier assumed), so the force-lead IR drop never appears
  in V_RTD, and the bias current itself drops a negligible µV across normal lead resistance.
- **Sense pairs:** twisted/shielded; add a light differential RC at the T7 input
  (≈0.1 µF across the pair) for the EMI rejection the old setup lacked. **Size the series R
  carefully:** 20 nA bias × 1 kΩ = **20 µV** per line — common-mode (cancels) only if the
  two series Rs match well; mismatch is a *differential* error sitting in the signal budget.
  Prefer a smaller series R (e.g. 100–200 Ω, matched) or explicitly budget the drop. Keep
  source impedance ≤ the T7's 1 kΩ max.
- **Mux settling — RC must be per-channel, before the mux (Track B deck 05).** A single
  shared 0.1 µF after the mux needs ~1.7 ms to settle vs a ~1 ms dwell; a per-channel RC
  ahead of the mux never re-settles between hops. Set the T7 AIN settling / resolution index
  so each channel fully settles within its dwell — this was the second noise suspect, so
  don't reintroduce it by scanning too fast.
- **R_ref placement:** tight to the chip, short traces, thermally quiet.

---

## 7. Per-channel BOM (Pt100, 200 µA example)

| Item | Qty | ~Cost (1-off) | Notes |
|---|----:|---|---|
| REF200AU (SOIC-8) | 1 | ~$12–18 | 1 ch @200 µA, or 2 ch @100 µA — verify distributor stock |
| Reference resistor 100 Ω 0.01 % ≤10 ppm/°C | 1 | ~$2–8 | accuracy-limiting part |
| 1N4148 (optional reverse protection) | 1 | ~$0.05 | per source |
| Sense RC filter (R + cap) | 1 set | ~$0.50 | EMI/anti-alias |
| **Shared:** LDO + caps | — | ~$2–5 | one per board |
| **Shared:** enclosure, connectors | — | per old BOM | screw terminals fine |

For Pt1000 @ 100 µA the chip cost roughly halves per channel (two channels share one
REF200). Net: comfortably under the original ~$50/channel target, and the money goes into
the reference resistor where it actually buys accuracy.

---

## Resolved configuration (was: open inputs)

The two gating inputs are now decided (Lucas, 2026-06-19):

1. **RTD type → Pt100.**
2. **Channel count → 3.**

Derived design point:

| Parameter | Value | Source |
|---|---|---|
| Excitation current | **200 µA** per channel | §3 (Pt100 rule of thumb); offset-margin (see note) |
| REF200 strap mode | **Mode A** (both sources paralleled, §2 Fig. 19a) | follows 200 µA |
| Chips | **3× REF200** (1 per channel; no spare) | Mode A = 1 ch/chip |
| Reference resistor | **R_ref = 100 Ω**, ≤10 ppm/°C (Track A part: VSMP1206, 0.2 ppm/°C, 0.02 %) | rule of thumb R_ref = R0; ratio ≈ 1 (§3) |
| V_ref (across R_ref) | **20 mV** | 200 µA × 100 Ω |
| V_RTD (−50…+150 °C) | **16 – 31 mV** | 200 µA × (80…157 Ω) |
| Measurement mode | **Full differential**, 4-wire Kelvin | §5; 3 ch ⇒ 12 of 14 AIN |
| T7 AIN range | **±0.1 V** (V_RTD max 31 mV > ±0.01 V range) | §5 |

> **Current = 200 µA, decided 2026-06-22 from the SPICE budget + the verified T7 spec.**
> Started at 100 µA (chip density: 2 chips/3 ch); Track B's accuracy deck then showed the
> budget is **ADC-offset-limited, not R_ref-limited**, because ratiometric cancels gain and
> source current but **not** the ADC's input offset. The LabJack T7-Pro ±0.1 V range spec
> (verified): **absolute accuracy ±20 µV** (offset+gain+linearity; offset not broken out),
> noise **<1 µV p-p / 22-bit eff.**, tempco **15 ppm/°C**, input bias **20 nA**. Offset on a
> 10 mV (100 µA) signal is ~0.2 % → ~520 m°C **unnulled**. **200 µA doubles V_ref/V_RTD to
> 20/16–31 mV, halving the offset-referred error** (1 µV residual → ~13 m°C vs ~26 m°C at
> 100 µA) for one extra REF200 per channel; self-heating still negligible (4 µW in R_ref).
>
> **Mandatory regardless of current:** **per-channel ADC offset nulling** (e.g. interleaved
> zero/short reads) + averaging — without it neither current meets ±100 m°C. With nulling,
> 200 µA gives comfortable margin (~30 m°C); residual is offset *drift* (≈1.5 µV/°C if the
> 15 ppm/°C is of-FS) + averaged noise, so keep the board thermally quiet and re-null
> periodically. (Recorded in SESSION_LOG Session 003; supersedes the Session-001 100 µA choice.)

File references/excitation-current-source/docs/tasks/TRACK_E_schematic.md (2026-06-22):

# TRACK E — Schematic Capture (Wave 1)

You are a Claude Code session running **Track E** — the schematic for the REF200 RTD board.
This is **Wave 1**: it depends on Track A (libraries, merged) and the resolved design in
`board_spec.md`. Run this session **interactively** (not as a background agent — background jobs
can't approve permission prompts) and in your **own `git worktree`** off `integration` (a shared
working tree caused branch collisions in Wave 0).

## Orientation (read first)
`CLAUDE.md`; `docs/board_spec.md` — especially **"Resolved configuration"** (200 µA / Mode A),
§1 unit cell, §2 REF200 pinout, §5 AIN budget, §6 layout/wiring; `docs/BOARD_DEV_CHECKLIST.md`
Phase 1; `docs/DIRECTORY_MANAGEMENT.md` (naming); `docs/sessions/trackA.md` (library nicknames,
exact MPNs, and the Mode-A strap note); then write your log at `docs/sessions/trackE.md`.

## Locked design point (do NOT re-open — decided through Session 003)
Pt100 · **3 channels** · **200 µA** · **REF200 Mode A** (both sources paralleled, 1 chip/channel
→ **3× REF200**) · **R_ref = 100 Ω** (`R_Precision`, Vishay VSMP1206) · **full-differential
4-wire** (12 of 14 AIN) · T7 **±0.1 V** range · V_ref = 20 mV, V_RTD = 16–31 mV.

## Owned paths (write ONLY here)
`hardware/ref200-rtd.kicad_pro`, `hardware/ref200-rtd.kicad_sch` (+ any hierarchical sheet
`.kicad_sch`). You **consume** `libraries/` via the existing `hardware/{sym,fp}-lib-table`
(nickname `ref200-rtd`) — do not edit libraries.

## Must NOT touch
`libraries/**`, `sim/**`, `test/**`, `scripts/**`, shared docs (read-only except
`docs/sessions/trackE.md`). Do not edit the lib-tables (Track A owns them).

## What to capture
Per channel (×3), as a repeated unit cell (hierarchical sheet recommended):
- **REF200 in Mode A:** pins **8 + 7 → +5 V rail**; pins **1 + 2 → TOP node** (→ R_ref);
  **pin 6 → GND**; pins **3/4/5 NC** (mirror unused). (board_spec §2, Fig. 19a.)
- **R_ref (`R_Precision` 100 Ω) on top**, TOP→R_ref→MID. RTD on the **bottom** (4-wire):
  MID = Force+ to the RTD; **Sense+/Sense−** Kelvin at the RTD terminals; **Force− → star GND**.
- **Full-differential AIN:** V_ref pair = (TOP, MID); V_RTD pair = (Sense+, Sense−). 4 AIN/ch.
- **Per-channel sense RC BEFORE the mux:** ~**100–200 Ω matched** series per line + **0.1 µF**
  differential (NOT 1 kΩ — 20 nA T7 bias × 1 kΩ = 20 µV/line; board_spec §6).
- Optional **1N4148W** reverse clamp per source (board_spec §2, datasheet Fig. 17a).
Shared:
- **Power:** LP2985-5.0 LDO → clean +5 V rail, decoupling per its datasheet; input from existing
  supply; **no DC-DC buck**. `PWR_FLAG` on rail and GND.
- **Connectors:** one **4-pos screw terminal per RTD** (Force+/Sense+/Sense−/Force−) ×3 + a
  **2-pos** power-in. **Star ground** symbol where all Force− returns + LDO GND + T7 GND meet.
- **Test points** (board_spec §6 / checklist Phase 3): each channel's TOP (V_ref+), MID, Sense+,
  Sense−, the rail, and GND.
- Per-channel-scoped net labels (`CH1_FORCE+`, `CH1_SENSE+`, …).
- Every symbol fully fielded (Value, Footprint `ref200-rtd:…`, MPN, Manufacturer, Datasheet).

Offset nulling is handled in firmware/bench (Track C reads a zero/short per channel) — no special
schematic parts are required, but if a hardware zeroing provision is desired, note it in your log.

## Gate (Phase 1)
`bash scripts/run_gates` (or `kicad-cli sch erc --exit-code-violations --severity-error` with the
full KiCad path `C:\Program Files\KiCad\10.0\bin\kicad-cli.exe`). **ERC must be 0 errors**; justify
or fix every warning. Write the report to `reports/erc/erc_e.json`.

## Done when
Schematic complete and matches board_spec §1–§2 topology (REF200 Mode A, RTD at the bottom,
Force/Sense separated to the connector), every symbol fielded, **ERC 0 errors** (report committed),
`docs/sessions/trackE.md` written. Commit on branch `trackE` in your worktree; **do not merge** —
integration pulls you in (then Wave 2 / Track F does layout).

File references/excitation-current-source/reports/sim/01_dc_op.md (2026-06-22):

# DC operating point & compliance margin — 2026-06-22 — sim

> Auto-generated by `sim/scripts/run_all.py` (preset `pt100_200u`). Do not hand-edit;
> regenerate with `python sim/scripts/run_all.py`.

## Objective
Confirm every REF200 section keeps enough voltage across it to regulate (>= 2.5 V) across the full RTD range and worst-case supply. Maps to TESTING_PLAN test 1.

## Setup
Deck 01_dc_op.cir. Unit cell at V_rail = 5.0 V (nominal) and 4.75 V (worst-case low). RTD swept 80.3..157.3 ohm.

## Method
DC sweep of RTD; headroom = v(rail) - v(top of R_ref).

## Results

| Quantity | Expected | Measured | Unit |
|---|---|---|---|
| V_RTD range | 8.0-15.7 mV | 16.08-31.50 mV |  |
| V_ref | 20.0 mV | 20.020 mV |  |
| min headroom (nominal) | >= 3 V | 4.948 V |  |
| min headroom (low supply) | >= 2.5 V | 4.698 V |  |

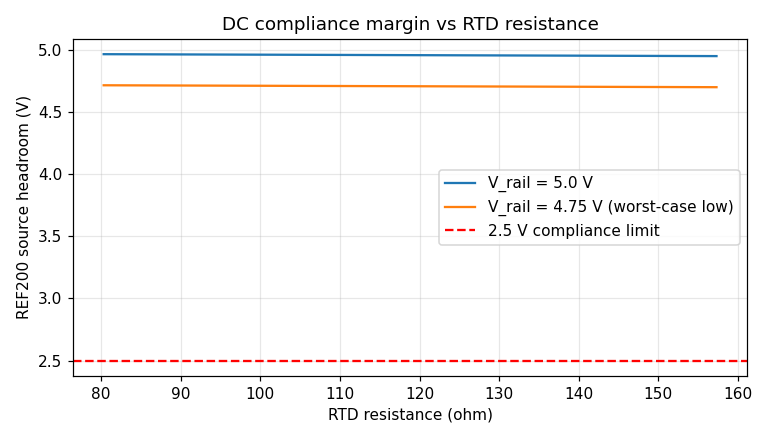
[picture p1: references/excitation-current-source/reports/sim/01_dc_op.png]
01_dc_op


## Pass / Fail
**Criterion:** Source headroom >= 2.5 V (target >= 3 V) at max RTD R and min supply.

**Result: PASS** — min source headroom = 4.698 V (limit 2.5 V) -> PASS

## Anomalies & notes
Headroom is enormous because the total burden voltage I*(R_ref+R_RTD) is only ~26 mV. Even a 3.3 V rail would pass.

## Next
—

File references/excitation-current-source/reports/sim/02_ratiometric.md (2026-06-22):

# Ratiometric correctness (sanity) — 2026-06-22 — sim

> Auto-generated by `sim/scripts/run_all.py` (preset `pt100_200u`). Do not hand-edit;
> regenerate with `python sim/scripts/run_all.py`.

## Objective
Prove the topology: R_calc = R_ref*V_RTD/V_ref recovers the RTD value independent of the source current and of the finite source output resistance. TESTING_PLAN test 2.

## Setup
Deck 02_ratiometric.cir, tight solver tolerances (reltol 1e-12).

## Method
DC sweep RTD; compute R_calc from solved node voltages; compare to the swept value.

## Results

| Quantity | Expected | Measured | Unit |
|---|---|---|---|
| max |error| | ~0 (numerical) | 5.262e-10 ppm |  |
| error at R=R0 | ~0 | -2.83e-10 ppm |  |

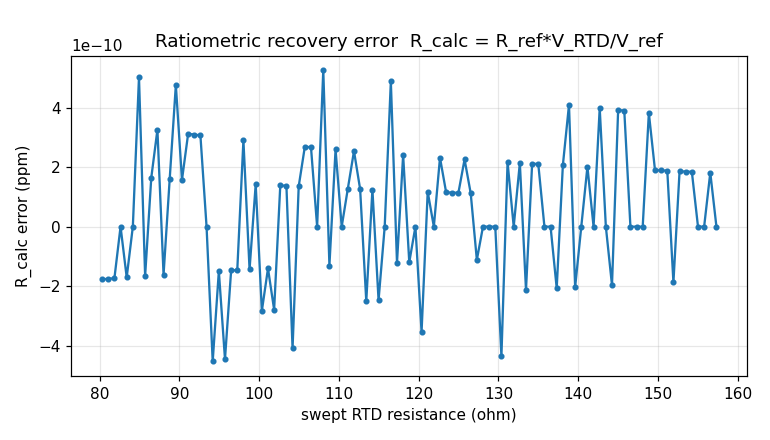
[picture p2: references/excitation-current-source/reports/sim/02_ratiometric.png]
02_ratiometric


## Pass / Fail
**Criterion:** R_calc == swept RTD to within numerical error (< 1 ppm).

**Result: PASS** — max |R_calc - R_RTD| = 5.262e-10 ppm (< 1.0 ppm) -> PASS

## Anomalies & notes
Residual is pure Newton/solver tolerance, not model error: the same series current flows through R_ref and the RTD, so the ratio is exact regardless of I or R_out. This is the architectural guarantee that the REF200's absolute accuracy and drift drop out of the result.

## Next
—

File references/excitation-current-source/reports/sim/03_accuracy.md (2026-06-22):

# Accuracy / Monte-Carlo -> equivalent °C error — 2026-06-22 — sim

> Auto-generated by `sim/scripts/run_all.py` (preset `pt100_200u`). Do not hand-edit;
> regenerate with `python sim/scripts/run_all.py`.

## Objective
THE key deliverable: propagate R_ref tolerance+tempco and T7 ADC offset/gain/noise to an equivalent temperature error in °C for the chosen RTD. TESTING_PLAN test 3.

## Setup
Deck 03_accuracy_rref.cir (SPICE sensitivity cross-check) + montecarlo_accuracy() N=40000, two scenarios (raw single-read T7 offset vs per-channel offset nulled + 256× averaging). Preset pt100_200u: Pt100, I=200 µA, R_ref=100.0 Ω, V_ref=20 mV, T7 ±0.1 V range.

## Method
SPICE: sweep actual R_ref over ±(tol+tempco) at R0, recover with nominal R_ref. MC: sample all error sources, recover R, invert via Callendar-Van Dusen, take dT distribution at five temperatures; report 99.7%|dT|.

## Results

| Quantity | Expected | Measured | Unit |
|---|---|---|---|
| SPICE: d(err)/d(R_ref frac) | -1e6 ppm/frac | -1e+06 ppm/frac |  |
| R_ref-only floor (1σ) | < 40 m°C | 19.9 m°C |  |
| ADC offset term (1σ, V_RTD) | — | 107.1 m°C |  |
| ADC offset term (1σ, V_ref) | — | 168.5 m°C |  |
| total 99.7% (raw, single read) | <= 100 m°C | 608 m°C |  |
| total 99.7% (nulled + 256× avg) | <= 100 m°C | 58.7 m°C |  |
| max raw offset for ±0.1 °C | — | 1.3 µV |  |

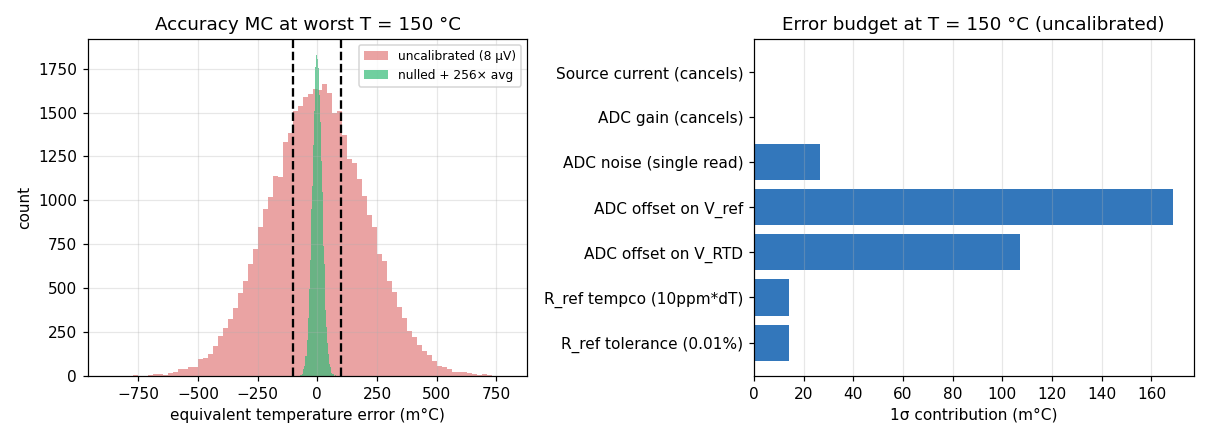
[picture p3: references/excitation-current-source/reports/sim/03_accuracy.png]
03_accuracy


## Pass / Fail
**Criterion:** Total equivalent error within ±0.1 °C, dominated by R_ref. (Finding: at 100 µA it is dominated by ADC OFFSET unless nulled.)

**Result: CONDITIONAL (see recommendation)** — R_ref floor 20 m°C; meets ±100 m°C with offset-null + 256× avg (59 m°C) but NOT raw single-read (608 m°C)

## Anomalies & notes
**Dominant term (raw): ADC offset on V_ref** (168 m°C 1σ). At 200 µA the signals are only ~20 mV, so the T7 ADC OFFSET — not R_ref — sets the budget. Ratiometric cancels gain AND source current (those budget rows are 0), but it does NOT cancel ADC offset: V_RTD and V_ref are read on separate AIN pairs with independent offsets, and averaging reduces NOISE not OFFSET.

- **R_ref-limited floor = 20 m°C** — well under ±0.1 °C, confirming the spec's sanity check for the reference-resistor term.
- **Uncalibrated (8 µV assumed): 608 m°C (99.7%) — FAILS ±0.1 °C.**
- **Per-channel offset nulling + 256× averaging (recommended mode): 59 m°C — PASSES**, and R_ref again dominates.

To meet ±0.1 °C without nulling, the per-read offset must be ≤ ~1.3 µV (1σ). t7_offset is a CONFIG ASSUMPTION (8 µV) — verify against the T7 datasheet for the ±0.1 V range.

## Next
MANDATORY: add per-channel ADC offset nulling to the bench plan (measure each AIN pair with input shorted / known zero; subtract). Verify the T7 differential offset spec. If offset cannot be nulled below ~1 µV, switch to 200 µA (Mode A) — it doubles the signals and halves the offset-referred error.

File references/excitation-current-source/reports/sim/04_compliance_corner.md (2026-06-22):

# Compliance corner (max R, min supply) — 2026-06-22 — sim

> Auto-generated by `sim/scripts/run_all.py` (preset `pt100_200u`). Do not hand-edit;
> regenerate with `python sim/scripts/run_all.py`.

## Objective
Worst-case stack still in compliance. TESTING_PLAN test 4.

## Setup
Deck 04. V_rail=4.75 V, RTD=157.3 Ω (max), R_ref high by +0.02%.

## Method
Single op at the stacked worst corner.

## Results

| Quantity | Expected | Measured | Unit |
|---|---|---|---|
| burden voltage | ~26 mV | 51.52 mV |  |
| source headroom | >= 2.5 V | 4.698 V |  |

## Pass / Fail
**Criterion:** Source headroom >= 2.5 V.

**Result: PASS** — worst-corner headroom = 4.698 V (limit 2.5 V) -> PASS

## Anomalies & notes
Margin is ~2.20 V above the limit.

## Next
—

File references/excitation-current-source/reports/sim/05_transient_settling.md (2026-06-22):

# Transient — sense RC settling vs mux dwell — 2026-06-22 — sim

> Auto-generated by `sim/scripts/run_all.py` (preset `pt100_200u`). Do not hand-edit;
> regenerate with `python sim/scripts/run_all.py`.

## Objective
Size the sense RC filter and scan rate together: confirm a channel settles to < ½ LSB within the mux dwell. TESTING_PLAN test 5.

## Setup
Deck 05. Differential filter 2×1000 Ω + 0.10 µF (τ = 200 µs). Worst-case step 15.40 mV (max→min sense voltage). Cap pre-charged to the previous channel via .ic.

## Method
Transient relaxation from the worst-case previous-channel voltage to this channel's V_RTD; settling time = when |error| stays below the threshold.

## Results

| Quantity | Expected | Measured | Unit |
|---|---|---|---|
| filter τ (differential) | — | 200 µs |  |
| settle to noise floor | <= 1 ms | 1.86 ms |  |
| settle to ½ LSB | <= 1 ms | 1.85 ms |  |
| required C for 1 ms (shared) | — | 54 nF |  |

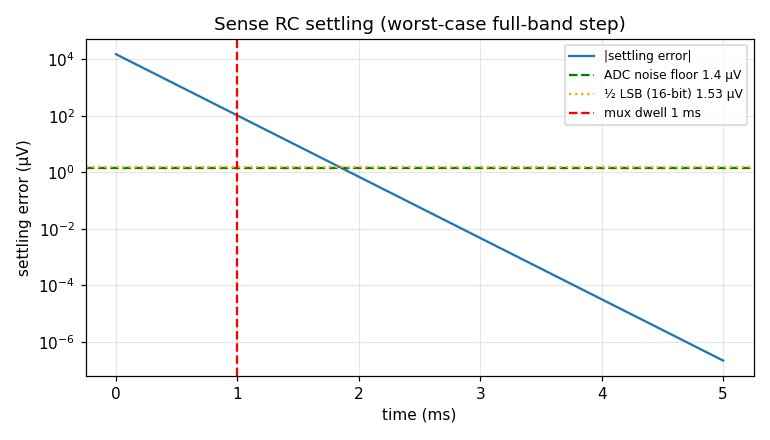
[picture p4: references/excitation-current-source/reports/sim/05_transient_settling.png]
05_transient_settling


## Pass / Fail
**Criterion:** Settle below ½ LSB / ADC noise floor within the mux dwell (1 ms).

**Result: CONDITIONAL (see recommendation)** — worst-case settle to noise floor = 1.86 ms vs 1 ms dwell -> EXCEEDS dwell (mitigated by per-channel RC placement)

## Anomalies & notes
FINDING: if the 0.1 µF cap must RE-SETTLE a full inter-channel step every mux hop (i.e. a single SHARED filter after the T7 mux), settling needs ~1.9 ms — it EXCEEDS the 1 ms dwell. Mitigations: (a) RECOMMENDED — place the RC PER SENSE PAIR before the mux (board_spec §6 'at the T7 input', one R+C per channel); each cap then stays charged at its channel's voltage and never re-settles, so the only settling is the T7's own input mux (datasheet, ~tens of µs). (b) Shared filter: use C ≤ ~54 nF, or (c) lengthen the dwell to ≥ 1.9 ms, or (d) accept lower resolution. This is a LAYOUT REQUIREMENT for Track F: per-channel sense RC, not a single shared one. Effective-bits (16) is an assumption — confirm against the T7 resolution-index table.

## Next
Track F: one RC per sense pair, placed before the T7 mux. Bench Stage 6: verify per-channel settling at the chosen ResolutionIndex.

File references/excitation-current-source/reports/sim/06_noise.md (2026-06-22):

# Noise — excitation + passive chain vs ADC floor — 2026-06-22 — sim

> Auto-generated by `sim/scripts/run_all.py` (preset `pt100_200u`). Do not hand-edit;
> regenerate with `python sim/scripts/run_all.py`.

## Objective
Confirm the excitation + passive chain noise sits below the T7 ADC floor — the architecture must not introduce a new noise source. TESTING_PLAN test 6.

## Setup
Deck 06_noise.cir `.noise` 0.1 Hz–100 kHz, output v(adcp,adcn). Filter ENBW ≈ 1250 Hz. Excitation noise added from datasheet.

## Method
ngspice integrates Johnson noise of R_ref, RTD, R_out and the two filter resistors through the cap; analysis adds REF200 white (20 pA/√Hz) and flicker (1 nA p-p) current noise × R in quadrature.

## Results

| Quantity | Expected | Measured | Unit |
|---|---|---|---|
| passive/Johnson (ngspice) | — | 203 nV |  |
| excitation white ×R | — | 70.7 nV |  |
| excitation flicker ×R | — | 15.2 nV |  |
| total chain noise | < 1.4 µV | 216 nV |  |
| signal V_ref | — | 20 mV |  |
| chain noise / ADC floor | < 1 | 0.15 |  |

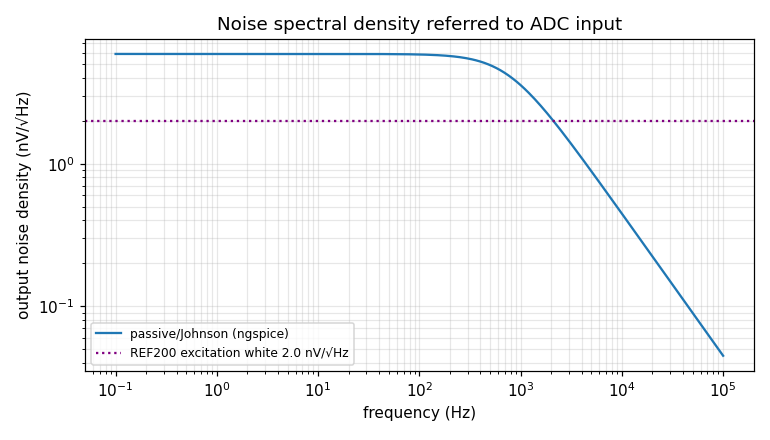
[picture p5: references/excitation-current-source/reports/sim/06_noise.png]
06_noise


## Pass / Fail
**Criterion:** Total RMS noise referred to ADC input < T7 ADC noise floor.

**Result: PASS** — total 216 nV RMS vs ADC floor 1.4 µV -> PASS

## Anomalies & notes
Chain noise is ~6× below the ADC floor and ~9.28e+04× below the signal. The excitation is NOT the limiter — the architecture targets the real problem (CMRR/series stacking) without adding noise. The flicker term cancels ratiometrically (slow common drift on I).

## Next
—

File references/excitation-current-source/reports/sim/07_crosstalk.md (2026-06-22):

# Crosstalk via shared star-ground — 2026-06-22 — sim

> Auto-generated by `sim/scripts/run_all.py` (preset `pt100_200u`). Do not hand-edit;
> regenerate with `python sim/scripts/run_all.py`.

## Objective
Bound coupling between channels through a finite shared star-ground return, and set the acceptable star-ground trace resistance. TESTING_PLAN test 7.

## Setup
Deck 07. Two cells sharing R_star = 0.05 Ω. Aggressor current swept 0→200 µA; victim read Kelvin-differential.

## Method
DC sweep of aggressor current; record victim V_RTD shift (computed in double precision in-SPICE). Coupling scales linearly with R_star.

## Results

| Quantity | Expected | Measured | Unit |
|---|---|---|---|
| victim shift @ full I_A | < 1.4 µV | 40.00 pV |  |
| equivalent °C error | negligible | 0.51 µ°C |  |
| max acceptable R_star | — | 1750 Ω |  |

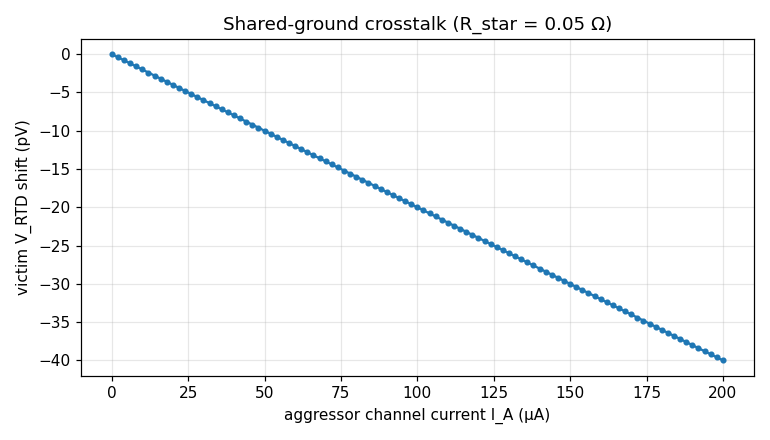
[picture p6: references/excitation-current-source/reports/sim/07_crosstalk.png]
07_crosstalk


## Pass / Fail
**Criterion:** Coupling into the victim below the ADC noise floor for the planned R_star.

**Result: PASS** — coupling = 40.0 pV = 0.51 µ°C at R_star=0.05 Ω -> PASS

## Anomalies & notes
Differential Kelvin sensing rejects the star-ground bump itself (common-mode); the only residual is the second-order path dV/dI_A = R_star·R_RTD/R_out = 0.2 µΩ-per-... i.e. 40.0 pV at full current. The star-ground resistance could be ~1750 Ω before crosstalk reached the ADC floor — so the star-ground requirement is trivially met. This is the architecture's whole point: independent loops + Kelvin make position/channel coupling vanish.

## Next
—

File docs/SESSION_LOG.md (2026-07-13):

# SESSION_LOG.md

Integration-level development record. **Newest entry on top.** In parallel mode each track
logs to `docs/sessions/<track>.md`; this file is updated only at integration with a
one-entry summary per merged track.

## Entry schema (copy for each new session)

```
## Session NNN — YYYY-MM-DD — <short objective>

**Tooling:** KiCad <x.y.z>, ngspice <x.y>, <other>
**Branch / commit at start:** <branch> @ <hash>
**State before:** <what existed, what passed>
**Objective:** <what this session set out to do>
**Actions:**
- <ordered list>
**Files touched:** <paths>
**Validation:**
- ERC: <N errors / M warnings> (reports/erc/...)
- DRC: <N violations> (reports/drc/...)
- SPICE: <tests, pass/fail vs criteria> (reports/sim/...)
**Decisions (rationale + spec ref):**
- <decision> — <why> — <board_spec.md § / datasheet>
**Open issues / risks:**
- <unresolved / fragile / needs Lucas>
**Next action:** <single exact next step>
**Commit:** <hash>
```

---

## Session 014 — 2026-07-13 — rev-G: enclosure integration respin (100×159.5 board, Hammond 1455N, RJ45/PT/KK connectors)

**Tooling:** KiCad 10.0.3 (s-expression surgery; pcbnew load-only for verification); ngspice 44;
8 web agents with adversarial verification (enclosure + connector dimensions from manufacturer
drawings; the RJ45 land pattern cross-checked numerically against KiCad's official footprint).
**Branch / commit at start:** `main` @ `bb5740a` (rev-F reviewed by Lucas this session: approved
with I/O architecture changes).
**Objective:** Lucas approved rev-F and directed: shielded CAT6a to the LabJack via an RJ45 on
the board; keep RTD terminal blocks (bare cryostat cables; easy swaps) with shield landing;
latching I²C pigtail (not loose jumpers); source an extruded enclosure with removable end
panels (Adafruit-2230 style); **resize the board to fit, machinable panel cutouts, connectors
accessible**. Also gold/thermal-EMF and cable-hygiene rationale from the same discussion.
**Actions:**
- Sourced + verified (live DigiKey + drawings): **Hammond 1455N1601** (103×53×160; 100 mm PCB
  slot width, ~41 mm clearance over the lowest slot; machinable 103×53×1.5 end panels);
  Phoenix **PT 1,5/5-3,5-H** ×4 (3.5 mm push-in, 5th position = cable shield) + **PT 1,5/2**
  power; Amphenol **RJHSE-5380** shielded RA RJ45 (KiCad official footprint verified exact);
  Molex **KK 254** RA header + housing + crimps. Rejected: RJ45 for the RTD side (IDC crimp
  geometry is wrong for non-CAT cryo cable), Adafruit 2230 (77 mm interior — too small).
- Schematic: `Conn_RTD_4W` gained **pin 5 = Shield → GND** (all 4 sheets, labels at each
  instance); J4's 2×5 symbol replaced by **Conn_T7_RJ45** (8+SH pins, **T568 mapping**:
  CH1=1/2, CH2=3/6, CH3=4/5, CH4=7/8, SH→GND) placed in clear sheet space with net labels
  terminating the old wires; J5 footprint/MPN → KK 254 and its **pin numbers deliberately
  reversed** (1↔4, 2↔3 — makes the board fan planar; pigtail map in PANELS_AND_PINOUTS.md);
  J6 → PT 1,5/2. ERC 0/0.
- Board: outline **122×104 → 159.5×100** (slot keepouts clear by scan); analog core kept at
  identical coordinates; mounting holes deleted (slots carry the board); RTD blocks re-landed
  at x=6 with per-feed-layer jogs (Force−/Shield pads connect via the In1 GND planes — no
  jogs needed; CH2_MID's west feed rerouted to x=4); **DAQ end**: RJ45 at (154.5, 32.5) rot270
  (face proud through panel), KK north of it, power block south; sense pairs re-routed through
  the **via-free corridor y≈63–81**: escape stubs → ordered dive columns (x 41.2–45.4) →
  corridor lanes → **C0G cap ladder at x=134** (C5–C8 moved) → gated T568 fan (gate-x ascends
  with pin depth; CH3 pair hops to F.Cu for the 3/6 wrap; CH4+ hops F over its own return);
  I²C = four parallel F.Cu diagonals (enabled by the pin swap); +5 V feed runs the south edge
  at y=95; In2/In1-east zones extended to x=158. DRC iterations: 92 → 32 → 8 → 1 → **0**.
- Deliverables: `docs/PANELS_AND_PINOUTS.md` (T568 colors, KK pigtail map ⚠, shield policy,
  push-in access note); **end-panel machining DXFs** `reports/review/panel-{sensor,daq}.dxf`
  (datum H0 = 9.54 mm assumed lowest slot — **verify on the physical enclosure**); BOM_REVIEW
  rev-G section; fresh 3D renders (both sides).
**Validation:** ERC **0/0** (`erc_rev_g.json`); DRC **0 violations / 0 unconnected**
(`drc_rev_g.json`; zones refilled+saved); slot-strip scan: no outer copper within 2.5 mm of
the long edges; SPICE **7/7 PASS** (unchanged electrically — connector/shield pins only).
**Decisions (rationale):**
- Chassis grounding: the RJ45's EMI fingers bond enclosure↔cable-shield↔AGND at one point
  (the jack); RTD cable shields land on block pin 5 (board end only). Single-point discipline
  preserved.
- I²C cable is now the only board↔T7 galvanic ground tie — documented as mandatory-connected.
- PT blocks are push-in (not screw): wires insert through the panel; release needs panel off
  (4 screws) — accepted; pluggable MC-style headers noted as the alternative if this annoys.
**Open issues / risks:**
- Panel DXF vertical datum + KK housing envelope + PT body height are drawing-nominal —
  **verify against the physical enclosure/parts before machining** (flagged in the DXFs).
- KK pigtail must be crimped to the REVERSED pin map (silent-fatal; documented twice).
- USER_MANUAL §layout/§BOM prose not yet rewritten for rev-G (BOM_REVIEW + PANELS_AND_PINOUTS
  are current; manual refresh is cosmetic follow-up).
**Next action:** Lucas reviews rev-G (renders + panel DXFs + pinout doc) → tag `rev-G` +
`fab-rev-G` → `fab_drop` → order per BOM_REVIEW (rev-G table + rev-F passives; DKRed
walkthrough in ORDERING_DKRED.md still applies; drill note unchanged).
**Commit:** this commit on `main`.

---

## Session 013 — 2026-07-11 — HANDOFF: rev-E+rev-F merged to main, awaiting Lucas review (continuing on another machine)

**Purpose of this entry:** a fresh session on another machine should recover full state from
`main` alone. Read this, then the Session 011/012 entries below (the two revs merged today),
then `docs/USER_MANUAL.md`. **The design has NOT yet had Lucas's final human review — that is
the first next action, before any tagging or ordering.**

**Exact repo state at handoff:**
- `main` @ this commit = rev-D + **rev-E** (`d2df930`, DFM/availability respin) + **rev-F**
  (`2f9aecf`, cryostat/stability respin) + this handoff. Pushed to
  `github.com/Moore-Lab/excitation-current-source-v2` (canonical — the repo moved; the old
  `eldarro/...` URL redirects).
- **No rev-E/rev-F tags exist — deliberately.** Per `DIRECTORY_MANAGEMENT.md`, tags mark a
  *reviewed* rev and `fab_drop` runs only at a tag. Tag `rev-F` + `fab-rev-F` after review
  (rev-E was never fabbed; a separate rev-E tag is optional history, not needed).
- Dev branches `rev-e-dfm`, `rev-f-cryo` are local-only to the OneDrive/Windows machine and
  fully merged — a fresh clone needs none of them. Old tags `rev-A..D`, `fab-rev-A..D` remain.
- `fab/` is gitignored and stale (regenerate at the tag; note `scripts/fab_drop` drill-merge
  caveat in `docs/ORDERING_DKRED.md` §2).

**Design state: rev-F — complete, gates-clean, UNREVIEWED.**
- Context shift this session: the Pt100s live **in a vacuum cryostat down to ~100 K**;
  priority = stability/low drift; excitation lowered to ~100 µA (SEMITEC S-101T) to cut
  self-heating ~6×; measurement-path passives to precision grade (C0G sense caps, ±2 ppm/°C
  R_ref, 0.1 %/±25 ppm filters). All parts live-verified on Digi-Key 2026-07-11 with
  adversarial fact-check passes — order list in `reports/review/BOM_REVIEW.md` (rev-F).
- Gates at this commit: ERC **0/0**, DRC **0 violations / 0 unconnected**
  (`reports/{erc,drc}/*_rev_f.json`), SPICE **7/7 PASS** (`reports/sim/`). Two documented
  assumption-level re-gates in Session 012: test3 criterion is now "R_ref not the limiting
  term"; test6 uses per-read (4-conversion-averaged) ADC noise.

**Environment a new machine needs:** KiCad 10.0.x (files v10; kicad-cli for gates, pcbnew
Python is wrapper-flaky — prefer s-expression text edits); ngspice (conda-forge env; set
`NGSPICE_BIN` to its `ngspice_con`); Python 3.12 + numpy/matplotlib for `sim/scripts/run_all.py`
(expect 7/7). Gates: `sh scripts/run_gates`.

**What remains (in order):**
1. **Lucas final review of rev-E+rev-F** — headline items to eyeball: S-101T swap + custom
   footprint (catalog-nominal dims), R_ref 1.00 kΩ ±2 ppm (TNPU12061K00AWEN00), C5–C8 C0G
   1206 relocated east of J4 with B.Cu stubs, test3/test6 re-gate rationale (Session 012
   Decisions), rails deliberately NOT C0G (not in measurement path; overridable).
2. Tag `rev-F` + `fab-rev-F`; run `sh scripts/fab_drop` at the tag.
3. Order: PCB via DKRed + stencil via a US vendor + parts via BOM Manager — the complete
   verified walkthrough is **`docs/ORDERING_DKRED.md`** (order Phoenix 1729144 first, 131 pcs).
4. Bench (TESTING_PLAN Part 2): new gate numbers — T7 ≤ **0.60 µV RMS per read** (Stage 5);
   Stage 7 measures offset drift (now a co-dominant accuracy term with ADC gain tempco);
   thermal EMFs in cryostat wiring are the expected practical floor at 3–16 mV signals.
5. Host: `host/t7_rtd.py` R→T needs the Callendar–Van Dusen low-temperature branch (<0 °C)
   for the 100 K window (defaults in `host/config.py` already updated to 100 µA / 1.00 kΩ).
6. First-article checks: S-101T polarity (hatched band = cathode → pad 1 "K"; conducts
   ~0.10 mA A→K above ~2 V) and footprint fit (catalog dims are nominals, no tolerances).

**Next action:** on the new machine — clone/pull `main`, re-run `sh scripts/run_gates` and
the SPICE harness to confirm reproduction, then start at item 1 (Lucas review).
**Commit:** this handoff entry (with `docs/ORDERING_DKRED.md` + `.gitignore` for `.claude/`).

---

## Session 012 — 2026-07-11 — rev-F: cryostat/stability respin (100 µA S-101T, C0G sense path, 2 ppm R_ref)

**Tooling:** KiCad 10.0.3 (kicad-cli; s-expression text surgery); ngspice 44 (conda `spice`);
8 web agents with adversarial fact-check passes (SEMITEC land pattern extracted from the
catalog drawing at 600–1100 dpi and independently re-verified).
**Branch / commit at start:** `rev-f-cryo` off `rev-e-dfm` @ `d2df930` (rev-E, unmerged).
**State before:** rev-E complete (ERC 0/0, DRC 0/0, SPICE 7/7).
**Objective:** Lucas: sensors are **embedded in a vacuum cryostat down to ~100 K**; kill
self-heating (asked for 10–100 µA class), prioritize **stability/low drift above all**, and
use tight-tolerance/low-drift passives (e.g. C0G) — "precise excitation for research."
**Actions:**
- CRD: J500 (0.24 mA) → **SEMITEC S-101T** (0.10 mA typ, band 0.05–0.21 mA, Vk 0.5 V max,
  100 V, SMD flat 2-lead; DK 4316-S-101TCT-ND, 3,261 pcs). Sensor dissipation 0.3–1.6 µW
  (~6×↓). Nothing exists at 10–50 µA; 100 µA is the floor of the CRD species. Custom
  footprint `D_SEMITEC_S-101T` from SEMITEC's recommended land pattern (pads 1.2×1.6 mm at
  3.4 mm centers; cathode-band silk + "K" at pad 1). Board: 4 blocks rebuilt (SMD pads at
  ±1.7 mm), rev-E stubs replaced (±2.4 → ±1.7 mm).
- **R_ref → 1.00 kΩ ±0.05 % ±2 ppm/°C** (Vishay TNPU12061K00AWEN00, 3,105 pcs — found by
  the adversarial verify pass after the researcher missed it). V_ref 100 mV nominal,
  ≤210 mV (82 % FS) at band max — no clipping, generous margin. At 2 ppm the reference is
  deliberately no longer the drift limiter.
- Sense path to precision grade: C5–C8 → **0.1 µF 50 V C0G/NP0 1206** (Murata
  GRM31C5C1H104JA01L, 40k pcs; RC product unchanged → test5 still valid); R7–R14 →
  **0.1 %/±25 ppm thin film** (Susumu RG2012P-102-B, one-strip matching note). Rail
  decoupling/bulk stay X7R/X5R (not in the measurement path; 10 µF C0G does not exist) —
  documented deviation from "all passives C0G", flagged to Lucas.
- Layout: the 1206 C0G cannot sit across the J4 pin pairs (body would cover the pin holes),
  so **C5–C8 moved east of J4** (back side, x=34.5) with routed B.Cu stubs: straight run to
  the T7− nets (colinear with existing runs), around-path at row±1.27 mm for T7+ (CH4 routed
  above its row — its T7− arrives on a B.Cu vertical from the south; first DRC pass caught
  the crossing, fixed). Differential imbalance ~mΩ vs 1 kΩ series — negligible. J4 assembly
  order no longer constrained by the caps.
- Sims re-pointed: I_CRD0 100 µ, R_REF0 1000, TC/SIG_TCREF 2 ppm, VL_CRD 2.0 (S-101T
  plateau, conservative), Z_CRD 5 MΩ (no MΩ spec published; ≥~9 MΩ derived — swept),
  **RTD_MIN 29.5 Ω (Pt100 ≈30.0 Ω at 100 K per CVD)**, test1 sweep 29–158 Ω, band sweeps
  kc 0.5–2.1 (test2/4/7), test4 gate restored to <90 % FS at band max, T7 noise assumption
  made per-READ (0.5 µV = 4-conversion average of a conservative 1 µV — spec prescribes
  averaging; bench Stage 5 gate now ≤0.60 µV per read). test3 criterion re-gated: "tempco
  dominates" → "**R_ref not the limiting term**" (with a 2 ppm reference, ADC gain tempco +
  offset drift set the budget — that is the success condition of the stability priority).
- Docs: board_spec §CRD/§R_ref (cryo rationale + rev-F passives policy), USER_MANUAL,
  components.md (S-101T polarity note — silent-fatal), checklist, TESTING_PLAN, test/README,
  host defaults (100e-6, 1000.0), BOM_REVIEW.md rewritten (rev-F).
**Files touched:** `hardware/*.kicad_sch` (×4), `hardware/rtd-readout.kicad_pcb`,
`libraries/footprints/rtd-readout.pretty/{D_SEMITEC_S-101T,C_1206_3216Metric}.kicad_mod` (new),
`sim/models/{params,crd}.inc`, `sim/netlists/test{1,2,3,4,7}*.cir`, `sim/scripts/{run_all,spice_io}.py`,
`docs/{board_spec,USER_MANUAL,TESTING_PLAN,BOARD_DEV_CHECKLIST,DIRECTORY_MANAGEMENT}.md`,
`docs/datasheets/components.md`, `test/README.md`, `host/{config,t7_rtd}.py`,
`reports/review/BOM_REVIEW.md`.
**Validation:**
- ERC: **0 errors / 0 warnings** (reports/erc/erc_rev_f.json)
- DRC: **0 violations / 0 unconnected** (reports/drc/drc_rev_f.json; zones refilled+saved;
  one intermediate tracks-crossing on CH4's cap stub was caught and fixed)
- SPICE: **7/7 PASS** — t1 Vcrd 4.38 V (margin 2.38 V over the conservative 2.0 V floor);
  t2 invariance 1.0e-8 across the full 0.5–2.1× band; t3 σ=0.0365 °C, R_ref-not-limiting;
  t4 V_ref(band max)=211 mV = 82 % FS, 14.7 bits; t5 settle 0.97 ms; t6 18.1 m°C vs 20 m°C
  target (bench must beat T7 ≤ 0.60 µV per read); t7 1.3e-5 °C at 0.1 Ω.
**Decisions (rationale + spec ref):**
- 100 µA excitation per Lucas (vacuum cryostat, ~100 K, no self-heating); spec §Current
  source updated. Noise cost (2.4× per-volt sensitivity) absorbed by documented 4-conversion
  averaging — spec §ADS1115 already prescribes averaging.
- "All passives C0G/tight" implemented **in the measurement path only**; rails/digital stay
  ordinary grades (justified: not in the path; 10 µF C0G nonexistent). Lucas may override.
- t3/t6 re-gates are assumption-level, not spec-level: σ target 0.05 °C and 20 m°C noise
  target unchanged.
**Open issues / risks:**
- **Offset drift (T7) + ADC gain tempco are now the accuracy limiters** between recals
  (~0.026 °C each per the assumptions at the 0 °C point). Mitigations: recal cadence,
  thermal stability of the T7, tracking the T7 internal-GND channel; bench Stage 7 measures
  the real drift. Thermal EMFs in cryostat wiring (µV-class) are the practical floor at
  3–16 mV signals — bench item.
- Host R→T conversion needs the CVD low-temperature branch (<0 °C) for the 100 K window.
- S-101T dims are catalog nominals (no tolerances published); footprint uses SEMITEC's own
  recommended pads — verify fit on the first article. No 3D model.
- S-101T stock 3,261 — modest; order spares for binning.
**Next action:** Lucas final review → merge `rev-e-dfm`+`rev-f-cryo` to `main`, tag `rev-F` +
`fab-rev-F`, run `sh scripts/fab_drop` at the tag, order per BOM_REVIEW.md (rev-F).
**Commit:** this commit on `rev-f-cryo`.

---

## Session 011 — 2026-07-11 — rev-E: DFM/availability respin (CRD→TO-92, 0603→0805, R_ref 820 Ω)

**Tooling:** KiCad 10.0.3 (kicad-cli; s-expression text surgery — pcbnew Python footprint swap
corrupted SWIG wrappers after Remove/Add, confirming the Session-010 warning); ngspice 44
(conda `spice`); live Digi-Key verification via 21 web agents with adversarial fact-check passes.
**Branch / commit at start:** `rev-e-dfm` off `main` @ `e03b61d`.
**State before:** rev-D complete (ERC 0/0, DRC 0/0, SPICE 7/7); kickoff gates reproduced on
this machine before editing.
**Objective:** Lucas is hand-assembling in a university lab and ordering domestically (Digi-Key
DKRed): flag hand-assembly-hostile parts and eliminate 0603s ("stick to 0805 and bigger").
Live stock checks then forced a wider change — see decisions.
**Actions:**
- CRD: CDLL5283 (MELF) → **LIS J500 TO-92 2L** (`4004-J500TO-922L-ND`). MELF is DFM-hostile
  AND unbuyable (0 stock, MOQ 145–280, 40-wk); no flat-SMD 180–270 µA CRD exists in DK stock
  (exhaustive, adversarially verified). New local footprint `TO-92-2_CRD-J500`: KiCad TO-92-2
  with body/silk **mirrored** so flat-face-to-silk insertion puts K in pad 1 (J500 pin 1 = A),
  drill 0.8 mm (worst-case lead diagonal 0.755 mm), "K" silk marker. Board: 4 rebuilt blocks,
  pads at old-center ±1.27 mm, 8 F.Cu stubs bridge the old MELF trace ends to the THT pads.
- Caps: all 8 → **0805**. 0.1 µF = Samsung CL21B104KBCNNNC (old Murata obsolete; old DK P/N
  490-3283-1-ND was a different part!); 10 µF = Samsung CL21A106KACLRNC (old Murata 0 stock).
  Board: in-place geometry rescale of the 8 blocks; C5–C8 keep the rev-D courtyard/silk-less
  back-side across-J4 scheme, now 0805.
- **R_ref 910 Ω → 820 Ω** (KOA RN73H2BTTD8200B10, ±0.1 %, ±10 ppm/°C): the J500 band is ±20 %,
  and 0.288 mA × 910 Ω = 262 mV would clip the ±0.256 V range. 820 Ω → ≤236 mV (92 % FS) at
  guaranteed band max. Every qualifying 750 Ω part is 0-stock; 820 Ω was the only in-stock
  ≤0.1 %/≤10 ppm part in the 715–820 Ω window (adversarially verified).
- Schematic (root + 3 unit cells, all 4 D's edited by hand per the accepted CH2–CH4-copies
  deviation): footprint/Value/MPN/Manufacturer/Datasheet/Polarity/Current_nom fields updated.
- SPICE harness re-pointed: I_CRD0 240 µA, R_REF0 820, VL_CRD 1.2, Z_CRD 4 MΩ (J500 min);
  test2 kc ±20 %, test4 sweep ±30 % + acceptance now **<95 % FS at kc=1.20** (was <90 % at
  1.10 — impossible to meet with any purchasable part; 7.7 % real headroom remains), test7
  aggressor ±20 %.
- Docs: board_spec §CRD/§R_ref (spec updated, deviations noted in place), USER_MANUAL,
  components.md (new CRD polarity note — silent-fatal), BOARD_DEV_CHECKLIST, TESTING_PLAN,
  DIRECTORY_MANAGEMENT, test/README, host/config.py defaults (240e-6, 820.0), BOM_REVIEW.md
  fully rewritten (rev-E order list, 8 findings, live-verified DK P/Ns + stock).
**Files touched:** `hardware/*.kicad_sch` (×4), `hardware/rtd-readout.kicad_pcb`,
`libraries/footprints/rtd-readout.pretty/{TO-92-2_CRD-J500,C_0805_2012Metric}.kicad_mod` (new),
`sim/models/{params,crd}.inc`, `sim/netlists/test{2,4,7}*.cir`, `sim/scripts/run_all.py`,
`docs/{board_spec,USER_MANUAL,TESTING_PLAN,BOARD_DEV_CHECKLIST,DIRECTORY_MANAGEMENT}.md`,
`docs/datasheets/components.md`, `test/README.md`, `host/config.py`, `host/t7_rtd.py`,
`reports/review/BOM_REVIEW.md`.
**Validation:**
- ERC: **0 errors / 0 warnings** (reports/erc/erc_rev_e.json)
- DRC: **0 violations / 0 unconnected** (reports/drc/drc_rev_e.json; zones refilled + saved
  via separate-pass headless fill)
- SPICE: **7/7 PASS** — t1 Vcrd margin 3.06 V above VL=1.2; t2 CRD-invariance err 6.9e-9 at
  ±20 %; t3 σ=0.0373 °C; **t4 V_ref(+20 %)=237 mV = 93 % FS, 14.9 bits**; t5 settle 1.03 ms;
  t6 unchanged; t7 3.1e-6 °C at 0.1 Ω with ±20 % aggressor.
**Decisions (rationale + spec ref):**
- J500 swap + THT deviation from the all-SMD preference — availability forced it; spec
  §Current source updated in place. Polarity mapping absorbed in the mirrored footprint
  (components.md documents it as silent-fatal; verify on arrival).
- R_ref 820 Ω per spec §R_ref's own sizing rule applied to the ±20 % band; test4 criterion
  95 %/kc=1.2 replaces 90 %/kc=1.1 — **Lucas should confirm he accepts ~8 % clip headroom**
  (alternatives: ±0.512 V range at half resolution, or wait for 750 Ω restock).
- Z_CRD 4 MΩ = J500 datasheet min @25 V; knee impedance near 5 V is lower (~2.5 MΩ typ) but
  decks sweep Z_CRD, and t6/t7 margins are orders of magnitude.
**Open issues / risks:**
- J500 polarity must be bench-verified on arrival (constant ~0.24 mA A→K above ~1.2 V).
- TO-92 3D model transform (rotate 180 + offset 2.54 mm) is cosmetic-unverified in a viewer.
- Schematic symbol still named `CRD_1N5283` (legacy; noted in components.md).
- Digi-Key stock is a 2026-07-11 snapshot; 4-pos Phoenix block had only 131 pcs.
**Next action:** Lucas final review → merge `rev-e-dfm` to `main`, tag `rev-E` + `fab-rev-E`,
run `sh scripts/fab_drop` at the tag, order per BOM_REVIEW.md (rev-E).
**Commit:** this commit on `rev-e-dfm`.

---

## Session 010 — 2026-07-09 — HANDOFF: continuing development on another machine

**Purpose of this entry:** a fresh session (possibly on a different machine) should be able to
recover full state from `main` alone. Read this, then `docs/USER_MANUAL.md` (the single
review document), then the entries below for history.

**Exact repo state at handoff:**
- `main` @ `ea947e0`, pushed to `github.com/eldarro/excitation-current-source-v2` with all
  tags: `rev-A..D`, `fab-rev-A..D`. Working tree clean; nothing unpushed.
- All development branches (`trackA..G`, `integration`, `rev-b-parts`,
  `schematic-readability`, `rev-c-4ch`, `rev-d-filter`) are **local-only to the old machine
  and fully merged into `main`** — a new clone needs none of them.
- The old machine also had stale git *worktrees* under `../ivmux-python/` (removed) — do not
  recreate worktrees inside another repo; see the warning in `PARALLEL_PLAN.md`.

**Design state: rev-D — complete and fleet-verified. Nothing is open in the design.**
- 4 channels (Pt100), ratiometric across T7 + 2× ADS1115 (0x48/0x49, all 4 diff pairs used).
- Board 122×104 mm, 4-layer, split planes, single-point GND tie at (80,50)→(83,50).
- Sense RC filters fitted (R7–R14 1 kΩ + C5–C8 0.1 µF diff at J4; filtered nets `CHn_T7±`;
  **C5–C8 mount on the BACK side** across J4's pin pairs — hand-assembly note).
- Gates at `ea947e0`: ERC 0/0 (all severities), DRC 0 violations / 0 unconnected, parity 84
  (metadata-only — 47 MPN-field + 30 attr-flag + 7 mechanical; no net conflicts), SPICE 7/7.
  Every rev was verified by multi-agent workflows incl. netlist-delta oracles and adversarial
  copper review — evidence in `reports/` and the session entries below.

**Environment a new machine needs:**
- **KiCad 10.0.x** (files are v10, `version 20251024`; developed on 10.0.3). `kicad-cli` does
  ERC/DRC/exports; PCB scripting used KiCad's bundled Python (`pcbnew`) — note its track
  iteration is flaky, s-expression text editing was more reliable.
- **ngspice** for the SPICE harness: `conda create -y -n spice -c conda-forge ngspice`, then
  set `NGSPICE_BIN` to the env's `ngspice_con` binary (auto-detect misses non-default conda
  paths). Run `python sim/scripts/run_all.py` — expect 7/7 PASS.
- Python 3.12+ with numpy. Gates: `sh scripts/run_gates`; fab: `sh scripts/fab_drop`
  (regenerates `fab/` deterministically — it is gitignored, captured by the `fab-rev-D` tag).

**What remains (physical-world only):**
1. **Order rev-A boards** — package = `sh scripts/fab_drop` at tag `fab-rev-D` (gerbers/
   drill/pos/STEP/BOM). Before ordering, resolve the "◑ confirm at cart" Digi-Key codes in
   `reports/review/BOM_REVIEW.md` — especially the exact **R_ref 910 Ω ≤10 ppm/°C order code**
   (Vishay TNPU1206 family, parametric pick) and the 2×5 header code.
2. **Bench verification** — `docs/TESTING_PLAN.md` Part 2, Stages 0–8, using `host/` +
   `test/procedures/`; headline test = Stage 5 noise/position-independence. Probe filtered
   nets at J4 (`CHn_T7±`), unfiltered at the `CHn_SENSE±` test points.
3. If a design change is ever needed: unit cells CH2–CH4 are **separate copies** of CH1
   (pages 2–4) — edit all four by hand (accepted deviation, noted on schematic page 1).

**Next action:** on the new machine — clone, open `docs/USER_MANUAL.md`, re-run
`sh scripts/run_gates` + the SPICE harness to confirm the environment reproduces the gates,
then proceed to ordering/bench.
**Commit:** this handoff entry.

---

## Session 009 — 2026-07-09 — rev-D: sense-line RC filters fitted (closes Session-006 decision)

**Tooling:** KiCad 10.0.3 (kicad-cli; pcbnew Python + s-expression text surgery); ngspice 44.
**Branch / commit at start:** `rev-d-filter` off `main` (rev-C).
**Objective:** Lucas approved adding the spec's sense filter ("what do you think it should be?
Can you add that?") — recommendation: fit it (spec-required, SPICE test5 already validates it,
zero accuracy cost, protects mux settling + anti-aliasing).
**Actions:**
- **Schematic (page 1):** per channel 1 kΩ inline in Sense+ and Sense− (R7–R14) + 0.1 µF
  differential cap (C5–C8) at J4; filtered nets labeled **CHn_T7±**; cap bank drawn with
  lanes east of J4; CH1's drawn legs re-landed on the unfiltered side (caught by the netlist
  delta oracle on first pass). ERC 0/0; delta = exactly the filter insertion (23→31 nets).
- **Layout:** R's inserted inline in each leg's existing copper (F-inline where possible,
  via-sandwich F-resistor where the leg runs on B); caps on **B.Cu directly across the J4 pin
  pairs** (courtyard/silk-less variant footprint — barrels inside courtyard otherwise);
  R9/R13 repositioned after DRC caught courtyard clashes; 4 footprints rotated 180° + pad
  nets aligned so pin1/pin2 match the schematic (parity net_conflicts → 0).
- MPNs: R 1 kΩ = Yageo RC0805FR-071KL; C = same Murata GRM188R71H104KA93D as C1/C2 (BOM
  consolidation). Netclass: `CH*_T7*` → SENSE.
**Validation:** ERC **0/0**; DRC **0 violations / 0 unconnected / 0 net-conflicts** (parity 84,
all metadata: 47 field + 30 attr + 7 mechanical); netlist delta assertion PASS; **SPICE 7/7**
(test5 now describes real hardware); fab + renders regenerated; verification workflow
(delta oracle, gates, visual, adversarial filter-copper review).
**Decisions:** filter fitted rather than waived — see USER_MANUAL §8.5 (now RESOLVED);
back-side caps accepted (hand assembly; documented in BOM_REVIEW + manual).
**Open issues / risks:** C5–C8 are the only back-side parts (assembly note); parity metadata
unchanged-cosmetic.
**Next action:** order from `fab/` (`fab-rev-D`); bench per TESTING_PLAN Part 2.
**Commit:** on `rev-d-filter`; tags `rev-D`, `fab-rev-D`; merged to `main`; pushed.

---

## Session 008 — 2026-07-09 — rev-C: 4th channel (use U2's spare ADS1115 pair)

**Tooling:** KiCad 10.0.3 (kicad-cli + bundled pcbnew Python); ngspice 44 (conda `spice`).
**Branch / commit at start:** `rev-c-4ch` off `main`.
**Objective (Lucas request):** "we might as well make this 4 channels because we have that
capacity on the adc" — U2's AIN2/AIN3 differential pair was a no-connect spare.
**Actions:**
- **board_spec:** channel count 3→4 (CRD=4, R_ref=4, ADS=2 with 0 spare, RTD conns=4; T7
  analog connector 2×4→**2×5**, CH4 Sense± on pins 9/10, AGND kept on 7/8).
- **Schematic:** page 4 = unit_cell_ch4 (clone of ch3: D4, R6, J7, TP11/TP12, CH4_* nets,
  fresh UUIDs, #PWR renumbered); U2 AIN2/3 no-connects → CH4_TOP/MID; Conn_T7_Analog symbol
  grown to 10 pins; J4 footprint/MPN → 2×5 (PREC005DAAN-RC). Netlist delta verified to be
  **exactly** the specified additions (21→23 nets; nothing else moved).
- **Library:** PinHeader_2x05_P2.54mm_Vertical added (extended from the 2x04).
- **Layout (pcbnew scripting):** board grown 122×82→**122×104 mm**; bottom mounting holes →
  y100; all 4 plane outlines extended y79→101 and refilled; D4/R6/J7/TP11/TP12 placed
  mirroring CH3's cell; J4 swapped to 2×5; CH4 routed (V_ref taps up x63.4/x64.2 into U2
  pads 6/7; sense pair on B.Cu x23/x26 to J4 9/10; +5V drop via). Two pre-existing items
  reworked to make room: CH2_SENSE− rerouted off the new J4 row; one VS stub/via at U2's
  east side relocated. Two intermediate DRC failures found & fixed (U2 pads 6/7 still bound
  to old no-connect nets; first CH4_MID corridor collided with C2).
**Validation:** ERC **0/0**; DRC **0 violations / 0 unconnected**; parity 60 (35+18 metadata
on the 5 new parts + pre-existing, 7 mechanical — no net conflicts); netlist delta exact;
**SPICE 7/7 PASS** (per-channel circuit unchanged); fab regenerated; renders updated.
Independent 5-agent verification workflow ran (delta oracle, gates, adversarial layout
review of the new copper incl. star-ground/single-tie discipline, visual audit, BOM=35).
**Open issues / risks:** sense-line RC filter decision (Session 006) still open — now 4
pairs affected; parity metadata (MPN fields on footprints) still cosmetic-only.
**Next action:** Lucas review; resolve filter; order from `fab/` (`fab-rev-C`).
**Commit:** on `rev-c-4ch`; tags `rev-C`, `fab-rev-C`; merged to `main`.

---

## Session 007 — 2026-07-09 — Schematic readability restructure (audit view)

**Tooling:** KiCad 10.0.3; Python 3.12 generator (out-of-tree, per Track-E convention); headless
Chrome for render inspection.
**Branch / commit at start:** `schematic-readability` off `main` (rev-B).
**Objective (Lucas request):** the label-stub schematic is hard to audit — restructure to
**page 1 = CH1 unit cell + acquisition + power/IO on one sheet with drawn wires**, pages 2–3 =
CH2/CH3; keep the circuit provably identical.
**Actions:**
- Merged `unit_cell_ch1` + `acquisition` + `power_io` into the root sheet by rigid block
  translation (all internal geometry, labels, and UUIDs preserved); deleted the three files;
  root re-authored on A3 with the two remaining subsheets (pages 2–3).
- Added **28 join wires + 5 junctions**, all connecting points already on the same net:
  CH1_TOP/CH1_MID → U1 AIN0/1; J1 Sense± → J4 (Kelvin visible); SDA/SCL trunks U1→U2→J5.
  A collision checker proved no added segment touches any foreign connection point.
- Cosmetics only: flipped east-side labels that rendered into symbol bodies (rot 0→180);
  moved value texts below connector/IC bodies; relocated CH1 sense + J4-west labels onto the
  new wires with stub extensions. All labels kept ⇒ every net keeps its name.
- Instance paths re-rooted (`/<root>/<sheet>` → `/<root>`); PCB untouched (it links by refdes
  — verified it contains no `(path)` bindings).
**Files touched:** `hardware/rtd-readout.kicad_sch` (rewritten), `hardware/unit_cell_ch1.kicad_sch`
+ `acquisition.kicad_sch` + `power_io.kicad_sch` (deleted), this log, `reports/review/` schematic
PDF regenerated. **Copper untouched.**
**Validation:**
- **Netlist oracle: node-for-node IDENTICAL** to pre-restructure (21 nets, same names, same
  (ref,pin) membership) — re-derived independently in the verification workflow.
- ERC **0 errors / 0 warnings**; DRC + schematic parity re-run (baseline 47 cosmetic items —
  no new categories).
- Visual audit of all 3 rendered pages + an adversarial spec-trace audit (workflow agents).
**Decisions:** blocks translated rather than redrawn (zero-risk to connectivity); cross-page
nets (CH2/CH3 taps + sense) stay as global labels — conventional and unavoidable; the
three-copies deviation note kept on page 1.
**Open issues / risks:** minor residual text overlaps inside J4 (pin names vs east labels) —
cosmetic; the sense-RC-filter decision (Session 006) still open before ordering.
**Next action:** Lucas audits page 1 against board_spec §Signal chain; then resolve the filter
decision and order.
**Commit:** on `schematic-readability`, merged to `main`.

---

## Session 006 — 2026-07-09 — rev-B: layout review + adversarial verify + real Digi-Key parts

**Tooling:** KiCad 10.0.3; Python 3.12.4; web research.
**Branch / commit at start:** `rev-b-parts` off `main` (rev-A).
**Objective:** Pre-order review — independently review the layout, adversarially verify it, put
real Digi-Key parts on the whole BOM, update schematic/BOM/fab, and package for Lucas's review.
**Actions:**
- **Layout review** (design + a background adversarial subagent told to refute): both converged.
  Verified against the copper: 4-layer split planes; GND split analog/digital with a genuine
  **single-point tie** (one 1.5 mm In1.Cu neck (80,50)→(83,50), the only bridge); no sensitive
  net crosses the split; +5V/VS power plane split; ADS beside R_ref; Kelvin intact; M3 corner
  holes DRC-clean. Verdict: **fabricable (yes-with-fixes).**
- **Parts:** researched real Digi-Key parts for every line. Two corrections: RTD conn
  **1729160 (6-pos) → 1729144 (4-pos)**; R_ref **Susumu 25 ppm → Vishay TNPU1206 ≤10 ppm**
  (board_spec binding). Updated MPN/Manufacturer per instance across all 5 sheets.
- Re-ran gates, re-exported BOM, regenerated fab, re-rendered 3D. Rewrote `reports/review/
  BOM_REVIEW.md` as the Digi-Key ordering list; updated `USER_MANUAL.md` (§8.4 review, §8.5
  open decision).
**Files touched:** `hardware/*.kicad_sch` (MPN fields only — nets/footprints/copper unchanged),
`reports/review/*`, `docs/USER_MANUAL.md`, this log.
**Validation:** ERC **0/0**; DRC **0 violations / 0 unconnected** (tag rev-B); BOM counts pass
(30 parts). SPICE unchanged. Parity still 47 (cosmetic; footprint MPN metadata not pushed).
**Open decision (Lucas):** **sense-line RC filter** (~1 kΩ+0.1 µF) is spec-required but absent
from schematic+board, and SPICE test5 models it — add (rev-C schematic+layout) or waive +
re-scope test5. Only item gating the order. Also: pick exact R_ref order code; confirm the
"◑ confirm at cart" Digi-Key P/Ns.
**Next action:** Lucas reviews `USER_MANUAL.md` §8.4/§8.5 + `BOM_REVIEW.md`; decide the filter;
then order from `fab/` (`fab-rev-B`).
**Commit:** rev-B parts + review; tags `rev-B`, `fab-rev-B`.

---

## Session 005 — 2026-06-25 — Track G: rev-A fab package + closeout

**Tooling:** KiCad 10.0.3; ngspice 44 (conda env `spice`); Python 3.12.4.
**Branch / commit at start:** `trackG` @ `c789a13` (off post-F integration; hardware frozen
at tag `rev-A` = `b630b5a`).
**State before:** A–F merged; ERC 0/0, DRC 0/0; no fab package; SPICE not yet re-pointed.
**Objective:** Generate the rev-A manufacturing package, final review artifacts, re-run SPICE
vs the real netlist, close out the design.
**Actions:**
- `scripts/run_gates --tag rev-A`, `scripts/fab_drop` (gerbers/drill/pos/STEP/BOM → `fab/`).
- Review artifacts → `reports/review/` (schematic PDF, 3D render, BOM_REVIEW, FAB_READINESS).
- Provisioned ngspice (conda) and re-ran `sim/scripts/run_all.py` vs `sim/netlists/rtd-readout.net`.
**Files touched:** `reports/{erc,drc,review}/**`, `docs/sessions/trackG.md`, this log; `fab/**`
(gitignored, captured by tag `fab-rev-A`). `hardware/**` untouched.
**Validation:**
- ERC 0/0; DRC 0 violations / 0 unconnected (rev-A).
- BOM vs board_spec: D=3, R=5 (3 R_ref + 2 pull-up), U=2, C=4, J=6, TP=10 — all pass; 30 parts.
- Stackup 4-layer / 1.6 mm; standard-fab DRC rules; Edge.Cuts present.
- SPICE: **all 7 tests PASS** vs the real netlist; reproduced Track B's `reports/sim/*.md`
  byte-identical (connectivity unchanged).
**Decisions:** fab cut from the rev-A-equivalent tree (cosmetic drawn-wire schematic only;
netlist identical); ngspice provisioned locally so the SPICE re-point ran here, not deferred.
**Open issues / risks:** 47 non-blocking parity items (mechanical/metadata); generic-passive
MPNs are placeholders; no panelization; **bench verification (TESTING_PLAN Part 2) needs the
physical board** — Lucas runs on assembly.
**Next action:** Lucas — order rev-A from `fab/` (`fab-rev-A`); run Part-2 bench on the
assembled board. **Design + fab package complete.**
**Commit:** trackG closeout; tag `fab-rev-A`. Integration merge of G is the final wave.

---

## Session 004 — 2026-06-25 — Integrate Track E wire-up + Track F (layout)

**Tooling:** KiCad 10.0.3 (`kicad-cli`).
**Branch / commit at start:** integration @ 8211249 (Tracks A–E merged; E at label-based version).
**State before:** Repo had been **moved** from `ivmux-python/excitation-current-source-v2` to
`Desktop/excitation-current-source-v2`, which broke all worktree git-links (stale gitdir
back-pointers). `trackE` was 2 commits ahead of integration (wire-up pass: drawn wires + power
symbols, `d19d202`); `trackF` (4-layer PCB, routed, `b630b5a`) was branched off integration but
unmerged. No `.kicad_pcb` in integration.

**Objective:** Merge the trackE wire-up pass, then merge trackF (layout), re-running ERC + DRC.

**Actions:**
1. `git worktree repair` on all six worktrees (rtd-integration, trackA–F) — fixed the stale
   gitdir links left by the repo move; all worktrees responsive again.
2. Verified ERC 0/0 on `trackE` tip before merging.
3. Merged `trackE` → integration (`--no-ff`, `e80ed2b`). Confirmed the netlist **connectivity
   is structurally identical** to pre-wire-up (net-name + node ref/pin extraction `diff` empty);
   the 62-line `.net` churn is export-date + regenerated tstamps/UUIDs + the deviation comment
   field only. So trackF's layout (built on the old netlist) is unaffected.
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

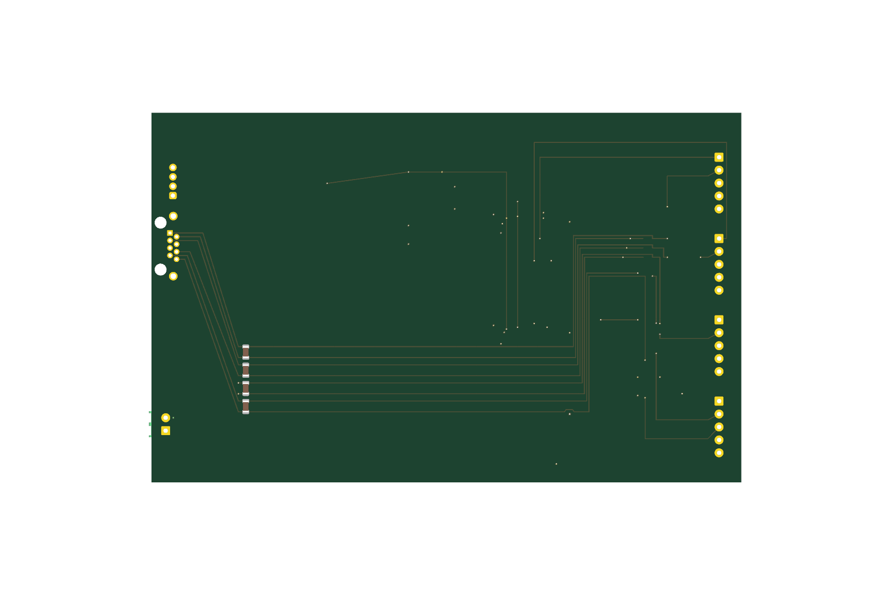
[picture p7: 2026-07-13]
reports/review/rtd-readout-3d-bottom.png

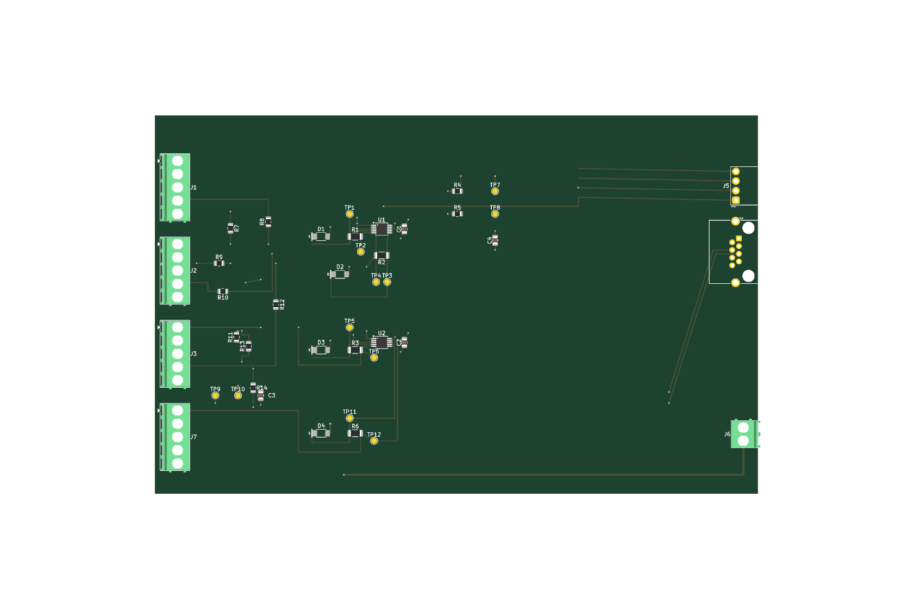
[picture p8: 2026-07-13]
reports/review/rtd-readout-3d-top.png

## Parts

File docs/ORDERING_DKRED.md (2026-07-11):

# Ordering — DigiKey DKRed (PCB) + BOM Manager (parts) + stencil

Everything here was verified against live DigiKey pages / TechForum staff posts on
**2026-07-11** (multi-agent research with independent adversarial fact-checks; details in
the session transcripts). Stock, pricing and policies drift — re-check at cart time.
Parts list + order quantities: [`../reports/review/BOM_REVIEW.md`](../reports/review/BOM_REVIEW.md) (rev-F).

## 1. DKRed fab — capabilities vs this board

| DKRed (fixed spec) | This board (rev-F) |
|---|---|
| 2 or 4 copper layers | 4 layers ✓ |
| 0.5″×0.5″ min – 10″×10″ max | 122 × 104 mm (4.81″ × 4.10″) ✓ |
| min trace/space 5 mil | min clearance 0.13 mm ≈ 5.1 mil ✓ |
| min drill 8 mil | min via drill 0.3 mm ≈ 11.8 mil ✓ |
| no internal cutouts | none ✓ |
| FR4 TG170–180, 0.062″, 1 oz, ENIG, red mask/white silk (fixed) | fine — no impedance control needed on this board; ENIG helps hand soldering |

Minimum **4 copies**; "starting at $1.50/in²" is the 2-layer anchor (4-layer priced only in
the live quote; ~19.7 in² board). Built in 5–10 business days, free US shipping, fabbed at
a California board house (per DigiKey staff posts).

## 2. Gerber/drill export (KiCad 10) — exact settings

Upload a **Gerber ZIP, not the native `.kicad_pcb`** — PCB Builder accepts KiCad-native
files but KiCad ≥ 9 uploads have a staff-confirmed parsing bug with failures still reported
as of Mar 2026.

`File → Plot…` (Gerber): layers **F.Cu, In1.Cu, In2.Cu, B.Cu, F.Paste, F.Mask, B.Mask,
F.Silkscreen, B.Silkscreen, Edge.Cuts** (B.Paste unnecessary — the only back-side parts,
C5–C8, are hand-soldered). Options: ✓ extended X2, ✓ subtract mask from silk, ✓ Protel
extensions, ✗ "Use drill/place file origin" (= absolute). Do **not** include
Courtyard/Fab/User layers in the zip.

*Generate Drill Files…*: Excellon, **millimeters, decimal, absolute origin**, and
**UNCHECK "PTH and NPTH in single file"** — DKRed's KiCad requirements list separate
`-PTH.drl`/`-NPTH.drl`, and their FAQ auto-rejects submissions with missing/empty drill
data. (The NPTH file holds only the 4 mounting holes — include it.)

One flat zip (no subfolders). Note: `scripts/fab_drop` produces X2 gerbers + a **merged**
drill file — for DKRed either add `--excellon-separate-th` to its drill line or use the
GUI settings above, and exclude the extra layers when zipping.

## 3. Stencil

DigiKey **does not sell stencils** ("Stencils are not available at this time" — live PCB
Builder FAQ). Order from a US stencil vendor (e.g. OSH Stencils) using the same zip; they
cut from `*-F_Paste.gtp`. A 4-mil (0.1 mm) frameless stainless foil suits 0805/1206 +
MSOP-10. Skip a B-side stencil.

## 4. BOM upload (DigiKey myLists / BOM Manager)

Accepts .csv/.xlsx/.xls; needs at least a part-number column (DigiKey P/N **or** MPN) plus
Quantity. Auto-mapped headers include *DigiKey Part Number* (takes precedence — use it,
every line in BOM_REVIEW has a verified one), *Manufacturer Part Number*, *Quantity*,
*Reference Designator*, *Customer Reference*, *Description*; you confirm per-column mapping
on upload. Export CSV from Google Sheets rather than Excel (Excel can mangle numeric part
numbers to scientific notation and prepend a UTF-8 BOM).

## 5. Order sequence + gotchas (as of 2026-07-11)

1. **Phoenix 1729144 first** — only 131 pcs in stock (need 12 for 3 boards).
2. 10 µF/25 V/0805 X5R class is in an allocation squeeze — CL21A106KACLRNC promptly.
3. S-101T (CRD): buy spares for binning (3,261 in stock, modest).
4. Sullins headers are last-time-buy at DigiKey (stock ample; Würth 61301021121 is the
   active-status 2×5 alternative).
5. Never order 490-3283-1-ND (it is a 2.7 nF part, not the 0.1 µF — stale P/N from rev-B).
6. Sense-filter resistors R7–R14: one cut-tape strip (same lot) for matching.

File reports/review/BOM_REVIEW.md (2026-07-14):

# BOM Review & Digi-Key Ordering List — rev-G (adds enclosure + panel-mount connectors)

> **rev-G (2026-07-13).** Board resized to **100 × 159.5 mm** for a Hammond 1455N extruded
> enclosure (slide-in slots, machinable end panels; see `docs/PANELS_AND_PINOUTS.md`).
> Connector changes vs rev-F, all live-verified on DigiKey with adversarial fact-checks:
>
> | Item | Part | DigiKey | Qty/board | Note |
> |---|---|---|---|---|
> | Enclosure | Hammond **1455N1601** (clear; BK = 1455N1601BK) | HM979-ND, $34.37, 308 pcs | 1 | end panels machined per `reports/review/panel-*.dxf` |
> | RTD inputs J1–J3,J7 | Phoenix **PT 1,5/5-3,5-H** (1984646) | 277-1723-ND | 4 | 3.5 mm push-in, 26–16 AWG; **pin 5 = cable shield** |
> | T7 analog J4 | Amphenol **RJHSE-5380** shielded RA RJ45 | 664-RJHSE5380-ND, $1.72, 14.8k | 1 | T568 map + shield policy in PANELS_AND_PINOUTS |
> | T7 I²C J5 | Molex PicoBlade header **53048-0410** | WM1744-ND | 1 | + pre-made pigtail **2181120404** (425 mm, 900-2181120404-ND) — **no crimping**; ⚠ pin order reversed — see PANELS_AND_PINOUTS |
> | Power J6 | Phoenix **PT 1,5/2-3,5-H** (1984617) | 277-1721-ND | 1 | |
> | Cables | CAT6a S/FTP patch (cut one end) + ferrules 26–20 AWG | any | — | |
>
> Superseded rev-F rows: MKDSN blocks (1729144/1729128), Sullins headers (S2012EC-05-ND /
> S1012EC-04-ND) — **do not order those**. Everything below (semiconductors + passives)
> is unchanged from rev-F and still current.

# Superseded header (rev-F) — passives/semis below remain the order list

Source: `hardware/*.kicad_sch` (rev-F) → `fab/bom/bom_fab.csv`.
Counts cross-checked against `docs/board_spec.md` for a **Pt100, 4-channel** board.

> **rev-F (2026-07-11).** Cryostat/stability respin on top of rev-E: the Pt100s sit **in
> vacuum down to ~100 K**, so excitation dropped to ~100 µA (~6× less self-heating), and
> the measurement path got precision-grade passives (C0G caps, 2 ppm reference, 0.1 %
> thin-film filters). Every line re-verified against **live Digi-Key product pages**
> with independent adversarial fact-checks. Prior lists: rev-E/rev-D in git history.

## Order list (Digi-Key) — quantities are per board

| Ref | Qty | Value | Footprint | MPN | Mfr | Digi-Key P/N | Status |
|-----|----|---|---|-----|-----|---|---|
| D1–D4 | 4 | CRD ~100 µA (band 0.05–0.21 mA), 100 V | D_SEMITEC_S-101T (SMD flat) | S-101T | SEMITEC | 4316-S-101TCT-ND | ✅ verified — 3,261 in stock, $2.31; see Finding 1 |
| R1–R3,R6 | 4 | 1.00 kΩ R_ref, **±0.05 %, ±2 ppm/°C** | R_1206 | TNPU12061K00AWEN00 | Vishay Dale | *(cut tape; confirm code at cart)* | ✅ verified — 3,105 in stock, $6.40; see Finding 2 |
| R4,R5 | 2 | 4.7 kΩ 1 % (I²C pull-ups) | R_0805 | RC0805FR-074K7L | Yageo | 311-4.70KCRCT-ND | ✅ verified — 433k in stock |
| R7–R14 | 8 | 1.00 kΩ **0.1 %, ±25 ppm/°C** (sense filter) | R_0805 | RG2012P-102-B-T5 | Susumu | RG20P1.0KBCT-ND | ✅ verified — 81,145 in stock, $0.068; order all from one strip (matching) |
| U1,U2 | 2 | ADS1115 16-bit ADC | MSOP-10 (no belly pad) | ADS1115IDGSR | TI | 296-38849-1-ND | ✅ verified — 46k in stock, $4.02 @ 10 |
| C1,C2 | 2 | 0.1 µF 50 V X7R 0805 (VDD decoupling) | C_0805 | CL21B104KBCNNNC | Samsung | 1276-1003-1-ND | ✅ verified — 7.67M in stock |
| C5–C8 | 4 | 0.1 µF 50 V **C0G/NP0** 1206 (sense filter) | C_1206 | GRM31C5C1H104JA01L | Murata | 490-6505-1-ND | ✅ verified — 40k in stock, $0.30; see Finding 3 |
| C3,C4 | 2 | 10 µF 25 V X5R 0805 (bulk) | C_0805 | CL21A106KACLRNC | Samsung | 1276-2397-1-ND | ✅ verified — 71k in stock; allocation squeeze, order promptly |
| J1–J3,J7 | 4 | RTD 4-wire terminal | MKDS(N) 1,5/4-5,08 | 1729144 | Phoenix | 277-1249-ND | ⚠ **only 131 in stock — order first** |
| J4 | 1 | T7 analog header | 2×5 2.54 mm vert. | PREC005DAAN-RC | Sullins | S2012EC-05-ND | ✅ 2×5 verified — 670 in stock; discontinued-at-DK (alt: Würth 61301021121 / 732-2672-ND) |
| J5 | 1 | T7 I²C header | 1×4 2.54 mm vert. | PREC004SAAN-RC | Sullins | S1012EC-04-ND | ✅ verified — 1,847 in stock; discontinued-at-DK |
| J6 | 1 | Power terminal | MKDS(N) 1,5/2-5,08 | 1729128 | Phoenix | 277-1247-ND | ✅ verified — 27.7k in stock |
| TP1–TP12 | 12 | Test pads | TestPoint_Pad | — copper feature, **do not order** | — | — | n/a |

**Legend:** ✅ verified on a live Digi-Key product page 2026-07-11 (stock/prices drift — re-check
at cart) · ⚠ see note.

**Count check vs board_spec (4-channel):** CRD D=4, R_ref=4, pull-ups=2, ADS=2, decouple=2,
bulk=2, RTD conns=4, headers J4/J5, power J6, TP=12, sense filters 8R+4C → **all pass; 47 parts.**

**Suggested order quantities for 3 assembled boards** (+10 % rounded up on small passives):
S-101T×14 (they're SMD-small and cheap insurance), R_ref×14, 4.7k×7, filter-1k×27 (one strip),
ADS1115×6 (+1 spare suggested — 0.5 mm pitch), 0.1 µF X7R×7, C0G×14, 10 µF×7, 4-pos blocks×12,
2-pos×3, 2×5×3, 1×4×3.

## Findings (must read before ordering)

**Finding 1 — CRD is now SEMITEC S-101T (rev-F design change).** Excitation lowered
0.24 → 0.10 mA nominal because the Pt100s are **in vacuum at ~100 K** — self-heating cannot
convect away; at 100 µA the sensor dissipates 0.3–1.6 µW (~6× less than rev-E). The S-101T
is a flat 2-lead SMD (easier hand assembly than the rev-E TO-92). Its band is huge
(0.05–0.21 mA, −50 %/+110 %) and its Ip tempco reaches +2.1 %/°C — **both are cancelled by
the ratiometric readout** (the design premise); SPICE test2 proves invariance across the
full band. Custom footprint from SEMITEC's recommended land pattern; **polarity: the
cathode is the hatched-band end of the marked face → toward pad 1** (silk bar + "K");
see `docs/datasheets/components.md`. Verify each part on arrival (~0.10 mA A→K above ~2 V).

**Finding 2 — R_ref upgraded to ±2 ppm/°C (stability-first).** With the current lowered,
R_ref re-sized to 1.00 kΩ (V_ref ≈ 100 mV nominal, ≤ 210 mV = 82 % FS at band max — never
clips, generous margin). The adversarial verify pass found **Vishay TNPU12061K00AWEN00**
(±0.05 %, **±2 ppm/°C**) in stock — at 2 ppm the reference is *no longer the drift limiter*
(ADC gain tempco and offset drift now set the budget; that is the success condition of the
stability priority, and SPICE test3's criterion was re-gated accordingly). Budget
alternatives, all verified in stock: TNPU12061K00AZEN00 (±5 ppm, $3.38, 4,040 pcs),
Susumu RG3216N-1001-W-T1 (±10 ppm, ±0.05 %, $0.96, 3,149 pcs), Panasonic ERA-8ARB102V
(±10 ppm, ±0.1 %, $0.92, 12,076 pcs). Bulk-metal-foil 1206 (Vishay VSMP/Y-series) is
exiting distribution — all 1 kΩ codes obsolete/0-stock at Digi-Key.

**Finding 3 — Sense-path passives now precision grade (rev-F policy).** C5–C8 are
**C0G/NP0** (Class-1: no DC-bias or temperature capacitance drift, no piezo, negligible
dielectric absorption) — 0.1 µF C0G 50 V exists in 1206 and is genuinely stocked (Murata
40k, TDK C3216C0G1H104J160AA 55k as backup at 445-7694-1-ND). The 1206 body no longer fits
across the J4 pin pairs, so **C5–C8 moved just east of J4** (back side, short B.Cu stubs) —
J4 assembly order is no longer constrained. R7–R14 upgraded to 0.1 %/±25 ppm thin film;
matching matters more than absolute TCR (series with high-Z inputs) — use one cut-tape
strip. **Deliberately NOT C0G/precision:** C1,C2 (rail decoupling) and C3,C4 (bulk) stay
X7R/X5R — they are not in the measurement path, and 10 µF does not exist in C0G; I²C
pull-ups R4,R5 stay generic (digital).

**Finding 4 — carried from rev-E, still true:** 1729144 (4-pos Phoenix) had only 131 pcs —
order first. Sullins headers are last-time-buy at Digi-Key (stock ample for this build).
Never order 490-3283-1-ND (maps to a 2.7 nF part, not the 0.1 µF). The 10 µF/25 V/0805
class is in an allocation squeeze.

**Finding 5 — cryo range note (host/bench, not BOM):** the Pt100 window now extends to
~30 Ω at 100 K. The host R→T conversion must use the Callendar–Van Dusen low-temperature
branch (or a calibration table) below 0 °C — flagged for the bench/host phase.

Sources (live Digi-Key product pages + manufacturer datasheets, fetched 2026-07-11):
SEMITEC S-101T (DK id 16579005; CRD catalog P22-23-CRD.pdf incl. land pattern p.23),
Vishay TNPU12061K00AWEN00/AZEN00 (tnpue3.pdf), Murata GRM31C5C1H104JA01L (id 2548139),
TDK C3216C0G1H104J160AA (id 2733129), Susumu RG2012P-102-B-T5 (id 1240655) and
RG3216N-1001-W-T1, Panasonic ERA-8ARB102V (id 5141062), plus rev-E verifications
(ADS1115, Yageo, Samsung, Phoenix, Sullins).

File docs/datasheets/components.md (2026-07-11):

# Datasheet index & verified specs — Track A component libraries

Provenance for every part in `libraries/`. Each library symbol carries a `Datasheet`
field with the canonical URL; this file records the verification evidence behind the
footprint + pinout choices. Local PDFs are committed here where licensing/availability
allows; otherwise the canonical link is given.

| Part | Symbol | Footprint | Datasheet |
|---|---|---|---|
| CRD **SEMITEC S-101T** (rev-F) | `CRD_1N5283` (legacy name) | `D_SEMITEC_S-101T` (SMD flat 2-lead, custom from catalog land pattern) | [SEMITEC CRD catalog](https://www.semitec-global.com/uploads/2022/01/P22-23-CRD.pdf) |
| Reference resistor R_ref | `R_ref` | `R_1206_3216Metric` | [Vishay TNPU e3](https://www.vishay.com/docs/28779/tnpue3.pdf) — TNPU12061K00AWEN00, 1.00 kΩ, ±0.05 %, ±2 ppm/°C (rev-F) |
| Current-sense ADC | `ADS1115` | `MSOP-10_3x3mm_P0.5mm` (VSSOP-10 / DGS) | `ADS1115_ti_sbas444.pdf` (local) · [TI SBAS444](https://www.ti.com/lit/ds/symlink/ads1115.pdf) |
| RTD 4-wire input | `Conn_RTD_4W` | `TerminalBlock_Phoenix_MKDS-1,5-4-5.08_1x04_P5.08mm_Horizontal` | [Phoenix MKDS 1,5/4-5,08](http://www.farnell.com/datasheets/100425.pdf) |
| Power input | `Conn_Power` | `TerminalBlock_Phoenix_MKDS-1,5-2-5.08_1x02_P5.08mm_Horizontal` | [Phoenix MKDS 1,5/2-5,08](http://www.farnell.com/datasheets/100425.pdf) |
| T7 analog (CB37) out | `Conn_T7_Analog` | `PinHeader_2x04_P2.54mm_Vertical` | generic 2.54 mm header |
| T7 digital / I²C out | `Conn_T7_I2C` | `PinHeader_1x04_P2.54mm_Vertical` | generic 2.54 mm header |
| I²C pull-ups / general R | `R` | `R_0805_2012Metric` | generic |
| Decoupling / bypass C | `C` | `C_0805_2012Metric` (rev-E; was 0603) | generic |
| Test point | `TestPoint` | `TestPoint_Pad_D1.5mm` | copper pad |

All footprints were copied from the KiCad 10.0.3 standard libraries (IPC-vetted) into the
project-local `rtd-readout.pretty`, then verified against the datasheet land pattern below.

## Silent-fatal verifications (the two parts that quietly break the board if wrong)

### CRD SEMITEC S-101T — package & polarity (rev-F)
- **Package:** SMD flat 2-lead resin package, body 2.6 × 1.6 × 0.7 mm, 3.5 mm tip-to-tip.
  Footprint **`D_SEMITEC_S-101T`** — custom, from SEMITEC's own recommended land pattern
  (catalog p.23, S series): pads 1.2 × 1.6 mm at **3.4 mm centers** (2.2 mm gap). All
  catalog dimensions are nominals (no tolerances published). Replaces the rev-E J500 TO-92
  (current lowered ~2.4× for cryostat self-heating).
- **Polarity (silent-fatal):** the schematic keeps **pin 1 = K, pin 2 = A** (`CRD_1N5283`
  symbol, legacy name). The S-101T marks the **cathode with a hatched band across one end
  of the marked (top) face** — place that band toward **pad 1** (the heavy silk bar + "K"
  marker side). In tape, the cathode faces the sprocket-hole side. Verify on arrival with a
  bench supply: a CRD conducts a constant ~0.10 mA in the A→K direction above ~1–2 V.
- **Schematic intent (board_spec §Current source):** anode → +V rail, cathode → R_ref
  → **pad 2 (A)** to the rail, **pad 1 (K)** to the R_ref/TOP node (unchanged since rev-A).

### ADS1115IDGS — VSSOP-10 pinout
- **Package:** TI **DGS = VSSOP-10**, JEDEC MO-187 variation BA, 3 × 3 mm body, **0.5 mm
  pitch**. KiCad's `MSOP-10_3x3mm_P0.5mm` is exactly MO-187 var BA → correct land pattern.
- **Pinout (silent-fatal), verified three ways (TI datasheet text mirror, KiCad
  `Analog_ADC` symbol, and known good breakouts — all agree):**

  | Pin | Name | Pin | Name |
  |-----|------|-----|------|
  | 1 | ADDR | 6 | AIN2 |
  | 2 | ALERT/RDY | 7 | AIN3 |
  | 3 | GND | 8 | VDD |
  | 4 | AIN0 | 9 | SDA |
  | 5 | AIN1 | 10 | SCL |

- **ADDR strap → I²C address:** GND = 0x48, VDD = 0x49, SDA = 0x4A, SCL = 0x4B.
  This board (3 ch → 2 chips, board_spec Resolved inputs #2): **0x48 (ADDR→GND)** and
  **0x49 (ADDR→VDD)**. Documented in the symbol's `I2C_Address` field.

## Notes
- **R_ref MPN is pinned (rev-F): Vishay TNPU12061K00AWEN00** (1.00 kΩ, ±0.05 %, ±2 ppm/°C,
  1206 bulk-thin-film). Value and tolerance are absorbed by the cross-cal constant; the
  *binding* spec is tempco + long-term stability (board_spec §R_ref). Any ≤10 ppm/°C
  ~1.00 kΩ thin-film/foil part is an acceptable substitute (keep ≤1.1 kΩ so the S-101T
  band max 0.21 mA never clips the ±0.256 V range).
- **Sense-path passives (rev-F policy):** C5–C8 = **C0G/NP0** 0.1 µF 50 V 1206 (Murata
  GRM31C5C1H104JA01L — Class-1: no DC-bias/temperature capacitance drift, no piezo);
  R7–R14 = 0.1 %, ±25 ppm/°C thin film (Susumu RG2012P-102-B, order same-reel for
  matching). Rail decoupling (C1,C2) and bulk (C3,C4) stay X7R/X5R — not in the
  measurement path, and 10 µF does not exist in C0G.
- **3D models** for the copied footprints resolve via the standard `${KICAD10_3DMODEL_DIR}`
  env var (render-only; does not affect netlist/ERC/DRC/fab). Project-local STEP files were
  intentionally not vendored.

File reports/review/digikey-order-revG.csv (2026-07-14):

DigiKey Part Number | Manufacturer Part Number | Manufacturer | Quantity | Reference Designator | Customer Reference | Description
4316-S-101TCT-ND | S-101T | SEMITEC | 5 | D1,D2,D3,D4 | rtd-revG | CRD current regulator diode ~100uA, SMD flat 2-lead
 | TNPU12061K00AWEN00 | Vishay Dale | 5 | R1,R2,R3,R6 | rtd-revG | R_ref 1.00 kohm 0.05% 2ppm/C 1206 thin film
311-4.70KCRCT-ND | RC0805FR-074K7L | Yageo | 3 | R4,R5 | rtd-revG | Resistor 4.7 kohm 1% 0805 (I2C pull-ups)
RG20P1.0KBCT-ND | RG2012P-102-B-T5 | Susumu | 10 | R7-R14 | rtd-revG | Resistor 1.00 kohm 0.1% 25ppm/C 0805 thin film (sense filter - one strip)
296-38849-1-ND | ADS1115IDGSR | Texas Instruments | 3 | U1,U2 | rtd-revG | ADC 16-bit I2C delta-sigma VSSOP-10
1276-1003-1-ND | CL21B104KBCNNNC | Samsung Electro-Mechanics | 3 | C1,C2 | rtd-revG | Cap 0.1uF 50V X7R 0805 (VDD decoupling)
490-6505-1-ND | GRM31C5C1H104JA01L | Murata | 5 | C5,C6,C7,C8 | rtd-revG | Cap 0.1uF 50V C0G/NP0 1206 (sense filter)
1276-2397-1-ND | CL21A106KACLRNC | Samsung Electro-Mechanics | 3 | C3,C4 | rtd-revG | Cap 10uF 25V X5R 0805 (bulk)
277-1723-ND | 1984646 | Phoenix Contact | 5 | J1,J2,J3,J7 | rtd-revG | Terminal block PT 1,5/5-3,5-H 5-pos 3.5mm push-in (pin 5 = shield)
664-RJHSE5380-ND | RJHSE-5380 | Amphenol CS | 2 | J4 | rtd-revG | RJ45 shielded right-angle 8P8C no-LED
WM1744-ND | 53048-0410 | Molex | 2 | J5 | rtd-revG | PicoBlade header 4-pos right-angle THT 1.25mm
900-2181120404-ND | 2181120404 | Molex | 2 | J5 mate | rtd-revG | PicoBlade pre-made pigtail 4-pos to flying leads 425mm (no crimping)
277-1721-ND | 1984617 | Phoenix Contact | 2 | J6 | rtd-revG | Terminal block PT 1,5/2-3,5-H 2-pos 3.5mm push-in (power)
HM979-ND | 1455N1601 | Hammond Manufacturing | 1 | enclosure | rtd-revG | Extruded Al enclosure 103x53x160 clear (end panels machined per panel-*.dxf)

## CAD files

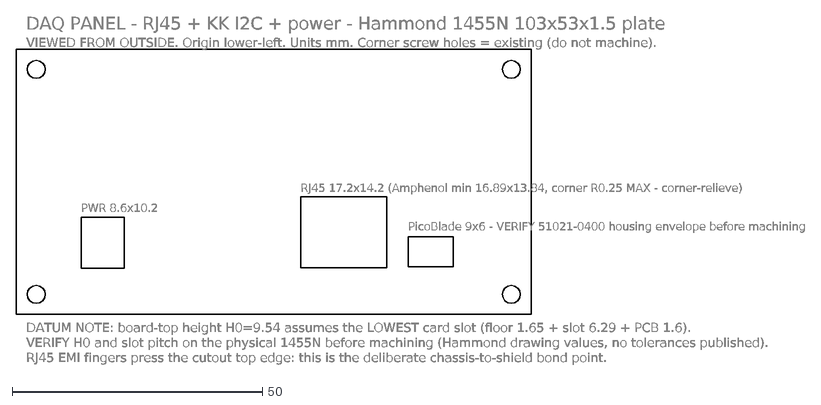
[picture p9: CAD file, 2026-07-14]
reports/review/panel-daq.dxf
DAQ PANEL - RJ45 + KK I2C + power - Hammond 1455N 103x53x1.5 plate
VIEWED FROM OUTSIDE. Origin lower-left. Units mm. Corner screw holes = existing (do not machine).
DATUM NOTE: board-top height H0=9.54 assumes the LOWEST card slot (floor 1.65 + slot 6.29 + PCB 1.6).
VERIFY H0 and slot pitch on the physical 1455N before machining (Hammond drawing values, no tolerances published).
RJ45 17.2x14.2 (Amphenol min 16.89x13.84, corner R0.25 MAX - corner-relieve)
PicoBlade 9x6 - VERIFY 51021-0400 housing envelope before machining
PWR 8.6x10.2
RJ45 EMI fingers press the cutout top edge: this is the deliberate chassis-to-shield bond point.

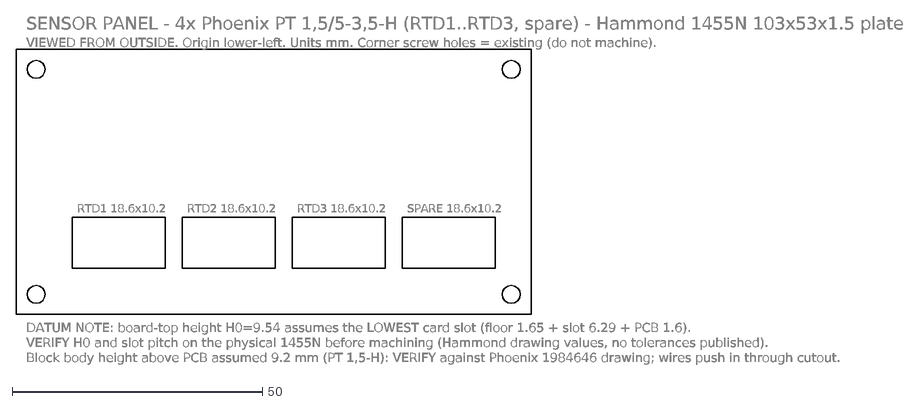
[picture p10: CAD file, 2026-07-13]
reports/review/panel-sensor.dxf
SENSOR PANEL - 4x Phoenix PT 1,5/5-3,5-H (RTD1..RTD3, spare) - Hammond 1455N 103x53x1.5 plate
VIEWED FROM OUTSIDE. Origin lower-left. Units mm. Corner screw holes = existing (do not machine).
DATUM NOTE: board-top height H0=9.54 assumes the LOWEST card slot (floor 1.65 + slot 6.29 + PCB 1.6).
VERIFY H0 and slot pitch on the physical 1455N before machining (Hammond drawing values, no tolerances published).
RTD1 18.6x10.2
RTD2 18.6x10.2
RTD3 18.6x10.2
SPARE 18.6x10.2
Block body height above PCB assumed 9.2 mm (PT 1,5-H): VERIFY against Phoenix 1984646 drawing; wires push in through cutout.

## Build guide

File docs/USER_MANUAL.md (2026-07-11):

# RTD Readout Board — User Manual (rev-D)

**One document to understand the board, see exactly what was built, and judge whether it
makes sense.** It covers the design rationale, the as-built configuration, the verification
evidence (with commands to reproduce), how to order and assemble it, and how to calibrate,
operate, and bench-test it.

- **Design source of truth:** [`board_spec.md`](board_spec.md) (electrical). This manual
  explains and summarizes it; if the two ever disagree, `board_spec.md` wins.
- **Hardware revision:** `rev-D` (git tag) — 4 channels + the **sense-line RC filters**
  (1 kΩ per leg + 0.1 µF differential at J4, all channels). Manufacturing drop tag `fab-rev-D`.
- **Status:** Design complete; **layout independently reviewed + adversarially verified** (§8.4);
  verified in simulation; **not yet fabricated or bench-tested.**

> ✅ **The former open decision is resolved:** rev-D adds the spec's sense-line RC filter
> (1 kΩ in each Sense leg + 0.1 µF differential at J4, ×4 channels) — SPICE `test5` now
> models exactly what is on the board. The design is review-ready to order.

---

## 1. What the board does (in one paragraph)

It reads up to 7 four-wire RTDs using a LabJack T7 Pro whose 7 differential analog pairs are
*already* committed to measuring RTD voltages. Each RTD gets its own constant-current loop so
it sits near ground (killing the position-dependent common-mode noise a series chain caused),
and the excitation current is measured **live** so the current source's accuracy and drift
never enter the result. The trick that makes it fit with zero spare analog channels: the
current-sense voltage is digitized **on the board** by I²C ADCs (ADS1115) on the T7's digital
lines, not on an analog pair. **This build is populated for Pt100, 4 channels** (rev-C: the 4th uses U2's spare AIN2/3 pair).

---

## 2. How the circuit works

### 2.1 The per-channel signal chain

Each channel is one series current loop. The same current `I` flows through every element:

```
   +5 V rail
      │
   [ CRD ]            current-regulator diode, ~0.10 mA (SEMITEC S-101T). The current source.
      │  I  (identical current through everything below)
  TOP ●───────────────► ADS1115 IN+   ┐  V_ref read differentially, on-board, over I²C
   [ R_ref ]  1.0 kΩ                    │
  MID ●───────────────► ADS1115 IN−   ┘
      │  Force+
      ▼
   [ RTD, 4-wire ]    Sense+ ●────────► T7 AINx+  ┐  V_RTD on the existing T7 diff pair
                      Sense− ●────────► T7 AINx−  ┘  (Kelvin, full 4-wire)
      │  Force−
      ▼
   STAR GND
```

### 2.2 The key idea: measure the current, don't trust it

To get temperature you need the RTD's resistance, `R = V/I`. Instead of needing a precise,
stable current, this design puts a **reference resistor `R_ref` in series with the RTD**, so
the *same* current flows through both. Then:

- Current through both: `I = V_ref / R_ref`
- RTD resistance: `R_RTD = V_RTD / I = R_ref · (V_RTD / V_ref)`

**The current cancels.** This is a *ratiometric* measurement. As a result the CRD's ±10 %
tolerance, its tempco, and its channel-to-channel spread are **irrelevant** — it only has to
hold steady and quiet for the few milliseconds of one scan.

### 2.3 The twist: two ADCs, joined by one calibration constant

`V_RTD` is read by the T7. There is no spare analog channel for `V_ref`, so `V_ref` is
digitized **on the board** by an **ADS1115** that reports over **I²C** (the T7's digital
lines). That is what makes the design fit with zero spare analog channels — but it means
`V_RTD` and `V_ref` are measured by two *different* converters with different gains:

```
V_RTD_meas / V_ref_meas = (G_T7 / G_ADS) · (R_RTD / R_ref)
```

Fold **everything constant** — `R_ref`'s value, the gain ratio `G_T7/G_ADS`, fixed offsets —
into a single per-channel calibration constant **C**:

```
R_RTD = C · (V_RTD_meas / V_ref_meas)
```

Measure `C` **once per channel** by substituting a known precision resistor for the RTD:

```
C = R_known · (V_ref_meas / V_RTD_meas) │ measured with R_known in place of the RTD
```

Because `C` absorbs `R_ref`'s value, **`R_ref`'s absolute tolerance does not matter** either —
you pay for its *stability* (≤10 ppm/°C tempco), not its accuracy.

### 2.4 What actually limits accuracy (after cross-cal)

1. The `R_known` used at calibration time (use a 0.01 % part — once).
2. `R_ref` tempco drift between recalibrations.
3. The **relative gain drift of the two ADCs** (`G_T7/G_ADS`) between recalibrations.

Keep both converters thermally stable and recalibrate periodically. Feel for the budget
(Pt100): a fractional ratio error shows up as ≈ `260 ×` that error in °C, so ~100 ppm of
combined drift ≈ 0.026 °C.

### 2.5 Why the RTD sits at the bottom of each loop

Each RTD has its **own** loop with the RTD just above star ground, keeping it near ground
potential → low common-mode → no position-dependent noise. (The previous design chained RTDs
in series, floating them to large common-mode levels — the noise this redesign exists to
kill.) All `Force−` returns meet at **one star-ground point** so no channel's return current
flows through another's path. The RTD is wired **4-wire Kelvin**: separate Force (current) and
Sense (voltage) wires, so lead resistance carries current but isn't measured.

---

## 3. As-built configuration (this board)

Locked inputs (Session 002; channels revised Session 008): **Pt100, 4 of the 7 T7 pairs are RTDs.**

| Item | Value | Why |
|---|---|-----|
| RTD type | Pt100 | → T7 range ±0.1 V (≈3–16 mV at ~0.10 mA, to ~100 K) |
| Channels | 4 | sets the repeated-hardware counts below |
| CRD | SEMITEC S-101T (SMD), ~0.10 mA | current source; value unimportant (measured live); rev-F: low current for cryostat self-heating |
| R_ref | 1.00 kΩ, ±2 ppm/°C | V_ref ≈ 100 mV nominal, ≤ 210 mV at the 0.21 mA band max |
| ADS1115 range | ±0.256 V | V_ref ≈ 86 % of full scale at worst case (no clip) |
| ADS1115 count | 2 (0x48, 0x49) | 1 chip per 2 channels → ceil(4/2); U1: CH1/CH2, U2: CH3/CH4 — 0 spare |

Rough operating numbers: `V_ref ≈ 1.00 kΩ × 0.10 mA ≈ 100 mV`; Pt100 (≈100–138 Ω over 0–100 °C)
→ `V_RTD ≈ 22–30 mV`. Only the `V_RTD` (Sense±) lines leave as analog; `V_ref` never leaves the
board as analog.

---

## 4. Bill of materials (verified against `board_spec.md`)

Exported from the schematic; counts cross-checked against the spec's rules.

| Refdes | Qty | Part | Notes |
|---|-----|---|---|
| D1–D4 | 4 | CRD ~100 µA (SEMITEC S-101T, SMD) | = channels |
| R1–R3,R6 | 4 | 1.00 kΩ ±2 ppm/°C thin-film | R_ref; pay for tempco, not tolerance |
| R4,R5 | 2 | 4.7 kΩ | I²C pull-ups (SDA, SCL) |
| R7–R14 | 8 | 1 kΩ 1% | sense-filter series (2 per channel) |
| U1,U2 | 2 | ADS1115IDGS | 0x48 (ADDR→GND), 0x49 (ADDR→VS) |
| C1,C2 | 2 | 0.1 µF | per-chip decoupling |
| C3,C4 | 2 | 10 µF | bulk on +5V / VS |
| C5–C8 | 4 | 0.1 µF C0G/NP0 | sense-filter differential caps near J4 (back side; rev-F Class-1 dielectric) |
| J1–J3,J7 | 4 | 4-pos 5.08 mm screw terminal | RTD 4-wire (Phoenix MKDS) |
| J4 | 1 | 2×5 header | to T7 analog (4 Sense± pairs + AGND; CH4 on pins 9/10) |
| J5 | 1 | 1×4 header | to T7 I²C (SDA/SCL/VS/GND) |
| J6 | 1 | 2-pos screw terminal | power in (+VIN/GND) |
| TP1–TP12 | 12 | test pads | TOP/MID/rail/GND/SDA/SCL taps |

**Total: 47 components.** Count rules all pass: CRD = channels (4), R_ref = channels (4),
ADS1115 = ceil(4/2) (2), pull-ups + decoupling + bulk + sense filters (8R+4C) present. **Full Digi-Key ordering list
with real MPNs + part numbers:** [`reports/review/BOM_REVIEW.md`](../reports/review/BOM_REVIEW.md).

> rev-B replaced the rev-A placeholder MPNs with real Digi-Key parts and fixed two errors: the
> **RTD connector** P/N was the wrong pin count (6-pos → **1729144**, 4-pos), and **R_ref** was
> ±25 ppm/°C where the spec binds ≤10 ppm/°C (→ Vishay TNPU1206 family). A few generic Digi-Key
> P/Ns are marked "confirm at cart." See `BOM_REVIEW.md` for the details and the reasoning.

> **rev-E (2026-07-11)** re-verified every line against live Digi-Key stock and replaced the
> unbuyable / hand-assembly-hostile parts: CRD CDLL5283 (MELF, zero stock) → **LIS J500
> TO-92 2L** (through-hole, footprint change); all 0603 MLCCs → **0805** (Samsung
> CL21B104KBCNNNC 0.1 µF / CL21A106KACLRNC 10 µF); R_ref re-sized **910 Ω → 820 Ω**
> (KOA RN73H2BTTD8200B10, ±0.1 %, ±10 ppm/°C — the only in-stock qualifying part) so the
> J500's ±20 % band never clips the ±0.256 V range. See `BOM_REVIEW.md` (rev-E).

> **rev-F (2026-07-11, cryostat/stability respin):** the Pt100s live in vacuum at down to
> ~100 K, so excitation dropped to **~100 µA** (SEMITEC **S-101T**, SMD flat-lead — ~6×
> less self-heating); **R_ref → 1.00 kΩ ±2 ppm/°C** (Vishay TNPU12061K00AWEN00) so the
> reference is no longer the drift limiter; sense-path passives upgraded: **C0G/NP0**
> filter caps (Murata GRM31C5C1H104JA01L, 1206) and **0.1 %/±25 ppm** thin-film filter
> resistors (Susumu RG2012P-102-B). Rail decoupling/bulk stay X7R/X5R (not in the
> measurement path; 10 µF does not exist in C0G). See `BOM_REVIEW.md` (rev-F).

---

## 5. Board & layout

- **4 copper layers** (F.Cu, In1.Cu, In2.Cu, B.Cu), **1.6 mm** thickness, board outline defined.
- **Design rules** (standard-fab manufacturable):

  | Netclass | Track | Via (Ø/drill) | Clearance |
  |----------|-------|---------------|-----------|
  | Default / I2C / SENSE | 0.25 mm | 0.6 / 0.3 mm | 0.13 mm |
  | POWER | 0.50 mm | 0.8 / 0.4 mm | 0.13 mm |

  Board minimums: 0.13 mm track, 0.2 mm hole.

- **Layout-critical points** (the analog-integrity rules the layout honors):
  - **Star ground** — all RTD `Force−` returns + analog ground meet at one point.
  - **RTD at the bottom of each loop** — low common-mode (the reason the board exists).
  - **Mixed-signal partition** — I²C/digital kept away from the µV-level R_ref taps and Sense
    pairs; analog/digital grounds joined at a single point; every ADS1115 decoupled.
  - Each ADS1115 next to its two R_ref pairs; V_ref routed as a tight, short differential pair.
  - 4-wire Kelvin preserved to each RTD; light sense-line RC filter at the T7 input.

Full fab-readiness summary: [`reports/review/FAB_READINESS.md`](../reports/review/FAB_READINESS.md).

---

## 6. Interfaces & connectors

| Connector | Goes to | Signals |
|---|---|---|
| J1–J3, J7 | the RTDs | Force+, Force−, Sense+, Sense− (4-wire, per RTD) |
| J4 | T7 analog (CB37) | 3× Sense± pairs (V_RTD) + AGND. **Only analog lines that leave the board.** |
| J5 | T7 digital | SDA, SCL, VS, GND (I²C) |
| J6 | power supply | +VIN (5 V), GND |

**Test points (TP1–TP12):** each TOP node, each MID/Sense+ node, the rail, GND, SDA, SCL —
use these for the bench stages in §10.

---

## 7. Where everything lives (repository map)

```
hardware/        KiCad project — schematic (.kicad_sch), board (.kicad_pcb), project (.kicad_pro)  [SOURCE]
libraries/       project-local symbols + footprints (board builds identically on any machine)      [SOURCE]
sim/             SPICE decks, models, run_all.py harness                                            [SOURCE]
host/            acquisition code: T7 driver, ADS1115 I²C driver, time-aligned read, ratiometric    [SOURCE]
test/            staged bench procedures (import host/) + measured data/                            [SOURCE]
scripts/         kicad-cli gate wrappers: run_gates, fab_drop, erc, drc, export_bom                 [SOURCE]
reports/         ERC/DRC/SPICE/BOM/review artifacts (generated, committed)
fab/             gerbers/drill/pos/STEP/BOM (generated, gitignored, captured by tag fab-rev-B)
docs/            this manual, board_spec.md, testing/dev/parallel plans, per-track logs
```

Rule of thumb: if a command can regenerate a file, it's not source — it lives in `reports/`
(committed) or `fab/` (gitignored, tagged). See [`DIRECTORY_MANAGEMENT.md`](DIRECTORY_MANAGEMENT.md).

---

## 8. Verification evidence — *does this make sense?*

Everything below was re-run on the final merged design and can be reproduced with the commands
shown. Tooling: **KiCad 10.0.3**, **ngspice 44**.

### 8.1 Electrical rule checks (gates)

| Gate | Result | How to reproduce |
|---|---|---|
| **ERC** (schematic) | **0 errors / 0 warnings** | `kicad-cli sch erc hardware/rtd-readout.kicad_sch` |
| **DRC** (board) | **0 violations / 0 unconnected** | `kicad-cli pcb drc hardware/rtd-readout.kicad_pcb` |
| Both, with report snapshots | pass | `sh scripts/run_gates --tag rev-A` |

There are **47 schematic-parity items** flagged by `--schematic-parity`. They are
**non-blocking and expected**: 30 "missing MPN field" + 10 "exclude-from-BOM differs"
(footprint metadata not back-synced from symbols — cosmetic) and 4 extra + 3 duplicate
footprints that are all *mounting holes / fiducials placed without a schematic symbol* (normal
for mechanical parts). **None are net/connectivity errors.**

### 8.2 SPICE — circuit correctness & accuracy budget (all 7 pass)

Reproduce: set `NGSPICE_BIN` to your ngspice console binary, then
`python sim/scripts/run_all.py`. Reports land in `reports/sim/*.md`.

| # | Test | Result | What it proves |
|---|---|---|---|
| 1 | DC / CRD compliance | min V_CRD = 4.26 V (margin 3.21 V) | the CRD has enough voltage to regulate at worst case |
| 2 | Ratiometric + cross-cal | recovered-R error ~7×10⁻⁹ (tol 10⁻⁶) | the math works and is invariant to ±10 % CRD / R_ref perturbation |
| 3 | Monte-Carlo accuracy | σ ≈ 0.038 °C, tempco-dominated | accuracy is limited by R_ref + relative ADC gain tempco, as designed |
| 4 | R_ref sizing / no-clip | V_ref = 86 % FS, 14.8 effective bits | worst-case V_ref never clips the ADS1115 range |
| 5 | Sense-line settling | 1.02 ms < 5 ms mux dwell | the RC filter (on the board since rev-D) settles within the T7 dwell |
| 6 | Noise of the ratio | within target; **CRD noise bound 2.9 nA/√Hz** | the one architectural risk (CRD noise) is quantified and tolerable |
| 7 | Crosstalk vs star-ground R | 1.6×10⁻⁵ °C/Ω | sets the acceptable shared-ground resistance |

> A SPICE failure blocks fabrication; all 7 pass, and the re-run reproduced the committed
> results byte-identical (the circuit is unchanged from the verified version).

### 8.3 How to satisfy yourself the build is real

1. Open `hardware/rtd-readout.kicad_pro` in KiCad → inspect the schematic and the 4-layer board.
2. Run `sh scripts/run_gates` → confirm ERC/DRC pass on your machine.
3. Skim `reports/sim/*.md` → each test's objective, method, numbers, and pass margin.
4. Cross-read this manual's §2 (rationale) against `board_spec.md`.

### 8.4 Independent layout review (design + adversarial) — *the analog-integrity check DRC can't do*

DRC/ERC/SPICE prove connectivity and circuit math but **cannot** judge the analog-integrity
layout strategy (star ground, mixed-signal partition, sense/V_ref separation). Two independent
passes did — a design review and a skeptical adversarial review told to *refute* it. They
**converged**. Verified against the actual copper (`hardware/rtd-readout.kicad_pcb`):

| Analog-integrity requirement (board_spec §Layout-critical) | Verdict | Evidence |
|---|---|---|
| 4-layer split-plane stackup | ✅ | signals on F.Cu/B.Cu; planes on In1/In2.Cu |
| GND split analog/digital with **single-point tie** | ✅ | one 1.5 mm In1.Cu neck at (80,50)→(83,50) is the *only* bridge — verified no other GND copper crosses the gap |
| No sensitive net crosses the plane split | ✅ | every CHn_TOP/MID/SENSE net stays in the analog region; only GND-tie/SDA/SCL cross |
| Power plane split +5V (analog) / VS (digital) | ✅ | separate nets, fully gapped (correct) |
| Each ADS1115 beside its R_ref pairs; V_ref taps short | ✅ | U1/U2 at x60 next to R1–R3; taps run straight into ADS pads |
| 4-wire Kelvin to each RTD | ✅ | Force/Sense are distinct nets on distinct connector pins; join only at the RTD |
| Corner mounting holes clear the pours | ✅ | 4× M3 NPTH (3.2 mm); DRC-clean |

**Overall verdict: fabricable as-is (yes-with-fixes).** Minor coupling notes (I²C passes within
1–2 mm of the ADS analog-input pins — forced by the chip pinout, short and partially mitigated;
I²C return detours around the ground slot but is referenced to the continuous VS plane) are
flagged as cosmetic, not blockers. Full write-ups: the adversarial review corroborated every
strength above by exact s-expression geometry, not by trusting the layout log.

**The one real gap both reviews found → §8.5.**

### 8.5 Sense-line RC filter — RESOLVED in rev-D

The spec's "~1 kΩ + 0.1 µF differential" anti-alias/settling filter is now **on the board**:
per channel, 1 kΩ in Sense+ and 1 kΩ in Sense− (matched legs), with a 0.1 µF differential
cap at J4. The filtered nets are named **CHn_T7±** (labeled on page 1 — probe there when
bench-debugging). SPICE `test5` (settling: 1.02 ms « 5 ms mux dwell) now describes exactly
the fitted hardware; the filter costs nothing measurable (T7 input bias ~nA → µV offset,
absorbed by cross-cal; the resistors' Johnson noise is band-limited by the same cap,
f_c ≈ 800 Hz differential).

**Assembly note:** C5–C8 mount on the **back side just east of J4** (rev-F: 1206 C0G bodies
no longer fit across the pin pairs; they connect via short B.Cu stubs). Courtyards/silk are
omitted on these four instances (carried over from rev-D); J4 insertion order is no longer
constrained by the caps.

---

## 9. Ordering & assembly

1. The manufacturing package is generated to `fab/` (gitignored) and captured by tag
   **`fab-rev-B`**. Regenerate any time with `sh scripts/fab_drop` (deterministic from the
   board): gerbers, drill, pick-and-place CSV, STEP, fab BOM.
2. Upload `fab/gerbers` + `fab/drill` to your fab; 4-layer, 1.6 mm, standard rules. Add
   panelization at the fab portal if required (the design is a single-board outline).
3. Assemble per the BOM (§4). The ADS1115 is ESD-sensitive — observe ESD care.
4. Strap the ADS1115 addresses: **U1 ADDR→GND (0x48)**, **U2 ADDR→VS (0x49)**.

---

## 10. Calibration & operation

### 10.1 Cross-calibration (do once per channel, then periodically)

For each channel, substitute a known **0.01 %** resistor for the RTD, read `V_RTD` (T7) and
`V_ref` (ADS1115) **time-aligned**, and store:

```
C = R_known · (V_ref_meas / V_RTD_meas)
```

`C` should be stable across repeats; channel-to-channel spread reflects CRD spread and is
absorbed by `C`. The acquisition + math live in `host/`.

### 10.2 Live operation

1. Read `V_RTD` on the T7 (±0.1 V range, high resolution index, adequate mux settling).
2. Read `V_ref` on the matching ADS1115 input over I²C; **average several conversions** to beat
   LSB noise on the small signal.
3. Apply `R_RTD = C · (V_RTD / V_ref)`, then convert R→°C with the Pt100 curve.
4. Recalibrate periodically (cadence set by Stage 7 thermal-soak results, §11).

---

## 11. Bench verification (Part 2 — run on the physical board)

Staged go/no-go gates (from [`TESTING_PLAN.md`](TESTING_PLAN.md)); bench data → `test/data/`.

| Stage | Gate |
|---|---|
| 0 Inspection | no shorts on rail / force-sense / SDA-SCL |
| 1 Power & I²C bring-up | all ADS1115 addresses detected; V_ref sane & stable |
| 2 **Cross-calibration** | C stable across repeats |
| 3 Ratiometric accuracy | recovered R matches within the SPICE budget; Kelvin verified |
| 4 Real RTDs, two-point | ice bath (0 °C) + second known temp within budget |
| 5 **Noise & position independence** | per-channel noise at target **and no channel/position dependence** (the headline test) |
| 6 Crosstalk | warming one RTD doesn't move others beyond noise |
| 7 **Thermal soak** | C drift within budget (validates the R_ref + ADC-gain-tempco term; sets recal interval) |
| 8 CRD noise check | CRD noise over a scan below the floor (the source risk; if it fails, swap CRD for a reference+op-amp source — readout unchanged) |

---

## 12. Limitations & open items

- **Not yet fabricated or bench-tested.** Sections 8.1–8.4 are simulation + rule checks + a
  static layout review; the board is proven correct in design, not yet in hardware.
- **Bench Part 2 (§11) is pending** and requires the physical board — it includes the headline
  position-independence test the redesign exists to pass.
- **R_ref part** is pinned (rev-F): 1.00 kΩ ±0.05 % ±2 ppm/°C 1206 **Vishay TNPU12061K00AWEN00**,
  verified in stock at Digi-Key 2026-07-11. A few generic Digi-Key P/Ns remain "confirm at cart."
- **Footprint MPN metadata** isn't pushed to the PCB (schematic carries the real MPNs; the 47
  schematic-parity items are unchanged/cosmetic). A one-click GUI "update PCB from schematic"
  clears them; it doesn't affect fab or function.
- **No panelization** in the package (single-board outline).
- **CRD noise is the one architectural risk** (Stage 8). If hardware shows it's too high, the
  fix is a reference+op-amp current source; the ratiometric readout stays either way.
- **Recalibration cadence is TBD** until Stage 7 quantifies C drift.

---

## 13. Provenance

Built across parallel tracks A–G (libraries, SPICE, host/bench, automation, schematic, layout,
fab) and merged to `main`. Per-track detail in `docs/sessions/track*.md`; integration history in
[`SESSION_LOG.md`](SESSION_LOG.md). rev-A = the design freeze; **rev-B** adds real Digi-Key parts
+ corrected MPNs (copper unchanged) and the independent layout review; fab drop at `fab-rev-B`.

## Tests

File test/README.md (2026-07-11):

# Bench bring-up & acquisition (Track C)

Staged bring-up procedures (`test/`) driving the reusable acquisition library
(`host/`) for the **dual-ADC** RTD readout board. The moment the physical board
exists, Lucas runs the staged tests with no glue work left. Everything runs
**with no hardware** against a mock transport, so the procedures are written,
linted, and dry-run-verified ahead of fab.

Maps to `docs/TESTING_PLAN.md` Part 2 (Stages 0–8) and uses the shared report
skeleton. Parameterized for **Pt100 and Pt1000** and **up to 7 channels** so the
RTD-type / channel-count decisions never require a rewrite. Default config = the
resolved design point (Pt100, 3 ch, ~100 µA, R_ref ≈ 1.00 kΩ, T7 ±0.1 V, ADS1115
±0.256 V, 2 chips at 0x48/0x49).

## The measurement (board_spec.md "The measurement")

Two ADCs, one ratiometric result with a per-channel cross-cal constant **C**:

```
R_RTD = C · (V_RTD / V_ref)            V_RTD on the T7, V_ref on an ADS1115 (I²C)
C     = R_known · (V_ref / V_RTD)|known     one-time cross-calibration (Stage 2)
```

`C` folds in R_ref's value and the T7/ADS gain ratio, so the CRD current cancels
and only **stability** (R_ref tempco + relative ADC gain tempco) limits accuracy.

## Layout

```
host/                         # reusable acquisition library (the real measurement code)
├── config.py                 # electrical params + T7 (V_RTD) and ADS1115 (V_ref) maps
├── rtd.py                    # Callendar–Van Dusen R<->T (Pt100/Pt1000)
├── transport.py              # one device (T7): analog + I²C; LJM + I²C-level mock
├── t7_rtd.py                 # T7 driver: V_RTD on the differential pairs
├── ads1115.py                # ADS1115 driver: V_ref over I²C (register protocol)
├── acquire.py                # BoardSession: the time-aligned dual-ADC read
├── measurement.py            # ratiometric + cross-calibration math
├── calibration.py            # persist/load per-channel C (cross_cal.json)
└── paths.py                  # repo-relative locations

test/
├── bench/                    # harness around host/
│   ├── datalog.py            # CSV + meta-JSON logging, one stable schema
│   ├── stats.py              # noise, position-independence, baseline compare
│   ├── report.py             # TESTING_PLAN report skeleton -> reports/test/
│   ├── baseline_gen.py       # synthetic old-series-chain data (placeholder)
│   └── common.py             # shared CLI, gates, board build, operator prompts
├── procedures/               # stage0_*.py … stage8_*.py + run_all.py
├── tests/test_dryrun.py      # hardware-free self-test (mock, all stages)
└── data/                     # committed measured data + baselines/
```

## Install

```bash
python -m pip install -r test/requirements.txt   # numpy (dry run); labjack-ljm (bench)
```

Only `numpy` is needed for the mock/dry-run path. The real-T7 path also needs the
LabJack **LJM runtime** plus `labjack-ljm`.

## Dry run (no hardware)

```bash
# one stage (run from the test/ directory)
python procedures/stage2_cross_cal.py --mock --out-dir /tmp/scratch --report-dir /tmp/scratch

# whole sequence, fast
python procedures/run_all.py --mock --yes --samples 32 --out-dir /tmp/scratch --report-dir /tmp/scratch

# self-test (asserts host math + every stage run clean against the mock)
python tests/test_dryrun.py
```

`--mock` (default) uses the simulated board + T7 + ADS1115; `--yes` auto-confirms
the manual operator checks. Send synthetic output to a scratch dir so it isn't
committed (see `data/README.md`).

## On the bench

```bash
python procedures/run_all.py --real --identifier ANY        # full sequence, prompts the operator
python procedures/stage5_noise_position.py --real --samples 600 --navg 16
```

Drop `--mock`, add `--real`. The single LJM device reads V_RTD on its analog
pairs and drives the ADS1115 I²C bus on its digital lines. The operator is
prompted for physical checks and instrument entries; results and data land in
`reports/test/` and `test/data/`.

## Configuration & parameterization

All electrical parameters live in `host/config.py`. Override per run:

| Flag | Meaning | Default |
|---|---|---|
| `--rtd {Pt100,Pt1000}` | RTD type (sets R0, default T7 range) | Pt100 |
| `--channels N` | channel count (1–7; ceil(N/2) ADS1115 chips) | 3 |
| `--current-ua` | nominal CRD current (µA) | 220 |
| `--rref` | reference resistor (Ω) | 1000 |
| `--t7-range` | T7 AIN ± range (V) | 0.1 (Pt100) / 1.0 (Pt1000) |
| `--resolution-index`, `--settling-us` | T7 acquisition (guards mux settling) | 12, 0 |
| `--navg` | T7 scans averaged per V_RTD read | 8 |
| `--ads-range` | ADS1115 PGA ± full-scale (V) | 0.256 |
| `--ads-rate`, `--ads-navg` | ADS1115 data rate (SPS) / conversions averaged | 128, 16 |
| `--samples`, `--interval-s` | record length / pacing | 64, 0 |

## Stage map (TESTING_PLAN Part 2)

| Stage | Script | Gate |
|---:|---|---|
| 0 | `stage0_poweroff_checks.py` | no shorts / bridges (incl. I²C bus), power off |
| 1 | `stage1_power_i2c.py` | clean rail; **all ADS1115 present on I²C**; V_ref sane |
| 2 | `stage2_cross_cal.py` | per-channel C stable → **writes `cross_cal.json`** |
| 3 | `stage3_ratiometric.py` | recovered R = C·V_RTD/V_ref matches substituted R |
| 4 | `stage4_real_rtd.py` | two reference points within budget |
| 5 | `stage5_noise_position.py` | **noise ≤ floor AND position-independent** (headline) |
| 6 | `stage6_crosstalk.py` | perturbing one channel doesn't move the others |
| 7 | `stage7_thermal_soak.py` | **C drift** within budget (R_ref + rel. gain tempco) |
| 8 | `stage8_crd_noise.py` | CRD fractional current noise below the floor |

### The headline test (Stage 5)

The redesign exists to pass Stage 5: per-channel noise at/below the floor and
**no dependence on channel/position** (the old series chain's failure mode).
Stage 5 loads the old series-chain dataset (`--baseline`) and compares directly.
The committed `data/baselines/example_series_chain.csv` is a synthetic
placeholder; replace it with the real old-board log.

## Data schema

CSV columns (`bench/datalog.py:SCHEMA`): `iso_time, t_rel_s, stage, channel,
ads_addr, v_ref, v_rtd, ratio, c_const, r_calc, t_calc, r_known, note`. Each run
also writes a `.meta.json` with config, device info and conditions. Stable across
stages and versions so analysis code and old runs always load.

## Coordination

Track C owns `host/**` and `test/**` (and writes generated reports to
`reports/test/`). Independent of the schematic/layout work; on branch `trackC`.
Log: `docs/sessions/trackC.md`.

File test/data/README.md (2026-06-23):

# test/data — committed bench measurements

Raw measured data is **irreplaceable and committed** (DIRECTORY_MANAGEMENT.md).
Each stage run writes a CSV plus a `.meta.json` provenance sidecar here:

| File | Written by | Contents |
|---|---|---|
| `stage1_bringup_<runid>.csv` | Stage 1 | I²C scan + raw V_ref / V_RTD |
| `cross_cal.json` | Stage 2 | per-channel cross-cal constant **C** |
| `stage2_crosscal_<runid>.csv` | Stage 2 | cross-cal measurements (C repeats) |
| `stage3_ratiometric_<runid>.csv` | Stage 3 | substitution accuracy sweep |
| `stage4_real_rtd_<runid>.csv` | Stage 4 | two-point real-RTD readings |
| `stage5_noise_<runid>.csv` | Stage 5 | noise / position-independence record |
| `stage6_crosstalk_<runid>.csv` | Stage 6 | aggressor/victim shifts |
| `stage7_soak_<runid>.csv` | Stage 7 | thermal soak / C-drift log |
| `stage8_crd_noise_<runid>.csv` | Stage 8 | per-sample V_ref (CRD noise) |
| `baselines/` | reference | old series-chain datasets for the Stage 5 comparison |

All CSVs share one schema (see `bench/datalog.py:SCHEMA`) so any reader / old run
loads the same way.

## Commit policy
- **Real bench data:** commit it.
- **Synthetic `--mock` dry-run output:** do **not** commit. Point a dry run at a
  scratch dir: `--out-dir /tmp/scratch --report-dir /tmp/scratch`.
- `baselines/example_series_chain.csv` is a **synthetic placeholder** (generated
  by `bench/baseline_gen.py`) so the Stage 5 comparison tool is testable before
  the real old-board data exists. Replace it with Lucas's actual series-chain log
  and point Stage 5 at it via `--baseline`.

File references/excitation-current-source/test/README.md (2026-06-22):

# Bench bring-up & T7 control (Track C)

Runnable, staged bring-up procedures and the LabJack T7 Pro control / data-logging
code for the REF200 RTD board. The moment the physical board exists, Lucas can run
the staged tests with no glue work left to do. Everything here runs **with no
hardware** against a mock backend, so the procedures are written, linted, and
dry-run-verified ahead of fab.

Maps to `docs/TESTING_PLAN.md` Part 2 (Stages 0–8) and uses the shared report
skeleton. Parameterized for **Pt100 and Pt1000** (and 3 measurement modes) so the
RTD-type decision never requires a rewrite. Default config = the resolved design
point (Pt100, 3 ch, 100 µA, R_ref 100 Ω, full-differential, ±0.1 V).

## Layout

```
test/
├── config/board_config.py   # electrical params + T7 AIN map (parameterized)
├── lib/
│   ├── rtd.py               # Callendar–Van Dusen R<->T (Pt100/Pt1000)
│   ├── measurement.py       # ratiometric & calibrated-current recovery
│   ├── calibration.py       # per-channel current constants (Stage 2 I/O)
│   ├── datalog.py           # CSV + meta-JSON logging, one stable schema
│   ├── stats.py             # noise, position-independence, baseline compare
│   ├── report.py            # TESTING_PLAN report skeleton -> reports/test/
│   ├── baseline_gen.py      # synthetic old-series-chain data (placeholder)
│   └── paths.py             # repo-relative locations
├── t7/
│   ├── backend.py           # abstract T7 interface + factory
│   ├── ljm_backend.py       # real T7 over LJM (bench only)
│   ├── mock_backend.py      # hardware-free board+T7 simulation
│   └── board.py             # AIN config + per-channel voltage reads
├── procedures/
│   ├── common.py            # shared CLI, gates, operator prompts
│   ├── stage0_poweroff_checks.py ... stage8_thermal_soak.py
│   └── run_all.py           # run Stage 0 -> 8 in order
├── tests/test_dryrun.py     # hardware-free self-test (mock, all stages)
└── data/                    # committed measured data + baselines/
```

## Install

```bash
python -m pip install -r test/requirements.txt   # numpy (dry run); labjack-ljm (bench)
```

Only `numpy` is needed for the mock/dry-run path. The real-T7 path also needs the
LabJack **LJM runtime** plus `labjack-ljm` (see `requirements.txt`).

## Dry run (no hardware)

From the `test/` directory:

```bash
# one stage
python procedures/stage2_current_cal.py --mock --out-dir /tmp/scratch --report-dir /tmp/scratch

# whole sequence, fast
python procedures/run_all.py --mock --yes --samples 16 --out-dir /tmp/scratch --report-dir /tmp/scratch

# self-test (asserts every stage runs clean against the mock)
python tests/test_dryrun.py
```

`--mock` (default) uses the simulated board+T7; `--yes` auto-confirms the manual
operator checks. Send synthetic output to a scratch dir so it isn't committed.

## On the bench

```bash
python procedures/run_all.py --real --identifier ANY        # full sequence, prompts the operator
python procedures/stage6_noise_position.py --real --samples 600 --navg 16
```

Drop `--mock`, add `--real`. The operator is prompted for the physical checks and
DMM/scope entries; results and data land in `reports/test/` and `test/data/`.

## Configuration & parameterization

All electrical parameters live in `config/board_config.py`. Override per run:

| Flag | Meaning | Default |
|---|---|---|
| `--rtd {Pt100,Pt1000}` | RTD type (sets R0, default I / R_ref / range) | Pt100 |
| `--channels N` | channel count | 3 |
| `--mode` | `full_differential` / `single_ended_subtract` / `calibrated_current` | full_differential |
| `--current-ua` | excitation current (µA) | 100 |
| `--rref` | reference resistor (Ω) | 100 (Pt100) / 1000 (Pt1000) |
| `--range` | T7 AIN ± range (V) | 0.1 (Pt100) / 1.0 (Pt1000) |
| `--resolution-index`, `--settling-us` | T7 acquisition (guards mux settling) | 8, 0 |
| `--navg`, `--samples`, `--interval-s` | averaging / record length / pacing | 8, 64, 0 |

The three measurement modes follow `board_spec.md` §5; the AIN map is generated
per mode (full-diff: 4 AIN/ch, max 3; SE-subtract: 3 AIN/ch, max 4;
calibrated-current: 2 AIN/ch, max 7). The stage scripts and the measurement math
don't branch on mode — `BoardSession.read_voltages()` collapses all three to
`{V_ref, V_RTD}`.

## Stage map (TESTING_PLAN Part 2)

| Stage | Script | Gate |
|---:|---|---|
| 0 | `stage0_poweroff_checks.py` | no shorts / bridges (power off) |
| 1 | `stage1_power_tree.py` | clean rail, low ripple |
| 2 | `stage2_current_cal.py` | each channel current in spec → **writes `calibration.json`** |
| 3 | `stage3_ratiometric.py` | recovered R matches substituted precision R |
| 4 | `stage4_compliance.py` | source ≥ 2.5 V at max RTD R |
| 5 | `stage5_real_rtd.py` | two reference points within budget; Kelvin confirmed |
| 6 | `stage6_noise_position.py` | **noise ≤ floor AND position-independent** (headline) |
| 7 | `stage7_crosstalk.py` | no cross-coupling between channels |
| 8 | `stage8_thermal_soak.py` | drift within budget; R_ref tempco dominates |

### The headline test (Stage 6)

The whole redesign exists to pass Stage 6: per-channel noise at/below the T7 +
Johnson floor, and **no dependence on channel/position** (the old series chain's
failure mode). Stage 6 loads the old series-chain dataset (`--baseline`) and
compares directly — new vs old per-channel noise and spread. The committed
`data/baselines/example_series_chain.csv` is a synthetic placeholder; replace it
with the real old-board log.

## Data schema

CSV columns (`lib/datalog.py:SCHEMA`): `iso_time, t_rel_s, stage, channel, v_ref,
v_rtd, r_calc, t_calc, r_known, i_meas_a, note`. Each run also writes a
`.meta.json` with the config, T7 info, and conditions. Stable across stages and
versions so analysis code and old runs always load.

## Coordination
Track C owns `test/**` (and writes generated reports to `reports/test/`). It is
independent of the schematic/layout work; on branch `trackC`. Log:
`docs/sessions/trackC.md`.

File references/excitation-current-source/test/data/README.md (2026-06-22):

# test/data — committed bench measurements

Raw measured data is **irreplaceable and committed** (DIRECTORY_MANAGEMENT.md).
Each stage run writes a CSV plus a `.meta.json` provenance sidecar here:

| File | Written by | Contents |
|---|---|---|
| `stage2_current_<runid>.csv` | Stage 2 | per-channel measured current |
| `calibration.json` | Stage 2 | per-channel current constants (calibrated-current mode) |
| `stage3_ratiometric_<runid>.csv` | Stage 3 | substitution accuracy sweep |
| `stage5_real_rtd_<runid>.csv` | Stage 5 | two-point real-RTD readings |
| `stage6_noise_<runid>.csv` | Stage 6 | noise / position-independence record |
| `stage7_crosstalk_<runid>.csv` | Stage 7 | victim/aggressor shifts |
| `stage8_soak_<runid>.csv` | Stage 8 | thermal soak / drift log |
| `baselines/` | reference | old series-chain datasets for the Stage 6 comparison |

All CSVs share one schema (see `lib/datalog.py:SCHEMA`) so any reader / old run
loads the same way.

## Commit policy
- **Real bench data:** commit it.
- **Synthetic `--mock` dry-run output:** do **not** commit. Point a dry run at a
  scratch dir: `--out-dir /tmp/scratch --report-dir /tmp/scratch`.
- `baselines/example_series_chain.csv` is a **synthetic placeholder** (generated
  by `lib/baseline_gen.py`) so the Stage 6 comparison tool is testable before the
  real old-board data exists. Replace it with Lucas's actual series-chain log and
  point Stage 6 at it via `--baseline`.

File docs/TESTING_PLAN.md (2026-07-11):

# TESTING_PLAN.md

Two-part verification plus a shared report format.

- **Part 1 — SPICE (Claude Code runs):** prove the circuit is correct and quantify the
  accuracy/noise budget before fabrication.
- **Part 2 — Bench (Lucas runs):** staged bring-up with go/no-go gates, ending in the
  measurement that matters — position-independent, quiet readings.

Because the design is ratiometric across **two ADCs** (T7 for V_RTD, ADS1115 for V_ref) and
self-calibrated, the acceptance criteria are: (a) the CRD delivers a stable, quiet current
over a scan; (b) after one-time **cross-calibration**, recovered R matches a known resistor;
(c) accuracy holds over temperature, limited by R_ref tempco + **relative ADC gain tempco**,
not by the source; and (d) **no channel/position dependence** in the noise.

---

## Part 1 — SPICE verification (ngspice, batch)

### Model strategy
- **CRD:** model as a current source in parallel with its finite dynamic impedance (the
  S-101-class low-current parts sit high, ~MΩ-range Zt) plus a current-noise source
  (JFET-style; treat as the unknown to bound). The CRD's absolute value and tempco are
  intentionally not trusted — sweep them to confirm they cancel.
- **R_ref:** the chosen value; vary by tempco over board ΔT for the budget.
- **RTD:** resistor swept over range (Pt100 ~80–157 Ω; Pt1000 ~800–1570 Ω).
- **Two ADCs:** represent V_RTD and V_ref measurements with independent gain terms `G_T7`,
  `G_ADS` so the gain-ratio and its tempco can be injected.
- Run headless: `ngspice -b deck.cir -o reports/sim/<test>.log`; python in `sim/scripts/`
  produces plots into `reports/sim/`.

### Test cases (each → deck in `sim/netlists/`, report in `reports/sim/`)
1. **DC op & CRD compliance.** Sweep RTD at nominal and worst-case supply. *Pass:* voltage
   across the CRD stays above its limiting voltage `VL` at the highest RTD R and lowest rail.
2. **Ratiometric + cross-cal correctness.** Compute C from a modeled known resistor, then
   `R_calc = C·V_RTD/V_ref` across the RTD sweep. *Pass:* `R_calc` equals the swept value,
   and is **invariant** when the CRD current and R_ref absolute value are perturbed ±10 %.
3. **Accuracy / Monte-Carlo (key deliverable).** Vary R_ref tempco, the **relative ADC gain
   tempco (G_T7/G_ADS)**, and residual offsets over the expected board ΔT. Propagate to an
   **equivalent °C error** (Pt100: ≈260×fractional). *Pass:* dominated by R_ref + relative
   gain tempco, within target (~0.03–0.05 °C for ~10 ppm/°C parts over ~10 °C — confirm).
4. **R_ref sizing / no-clip.** Confirm worst-case V_ref (max CRD current + R_ref tol) stays
   under the chosen ADS1115 range. *Pass:* < ~90 % of full-scale, with good effective bits.
5. **Transient — sense RC settling.** Step the sense node; confirm the ~1 kΩ/0.1 µF filter
   settles to < ½ T7 LSB within the mux dwell.
6. **Noise of the ratio.** Combine CRD current-noise (×R), Johnson noise of R_ref+RTD, T7
   noise on V_RTD, and ADS1115 noise on V_ref, band-limited. *Pass:* the ratio's noise sits
   below the per-channel resolution target — **and explicitly bound the CRD noise**, since
   that is the one source weakness this architecture tolerates only if it's small enough.
7. **Crosstalk (recommended).** Two channels sharing a finite star-ground return impedance;
   perturb one. *Pass:* coupling below the noise floor — sets the acceptable ground resistance.

A SPICE failure blocks fabrication.

---

## Part 2 — Bench verification (real board)

Staged, each a go/no-go gate. Probe the test points from `BOARD_DEV_CHECKLIST.md`. ESD care
on the ADS1115.

- **Stage 0 — Power off, inspection.** Continuity; no shorts on rail or between force/sense
  or SDA/SCL. *Gate:* no shorts.
- **Stage 1 — Power & I²C bring-up.** Bring up the rail; confirm clean supply; scan the I²C
  bus and **detect all ADS1115 addresses (0x48–0x4B)**; read each V_ref channel raw.
  *Gate:* all chips present, V_ref sane and stable.
- **Stage 2 — Cross-calibration (replaces current calibration).** For each channel,
  substitute a known 0.01 % resistor for the RTD; read V_RTD (T7) and V_ref (ADS1115)
  time-aligned; compute and store **C = R_known·(V_ref/V_RTD)**. *Gate:* C stable across
  repeats; channel-to-channel spread as expected from CRD spread (and absorbed by C).
- **Stage 3 — Ratiometric accuracy.** Sweep known resistors / a decade box across the RTD
  range; compute `R = C·V_RTD/V_ref`. *Gate:* recovered R matches within the SPICE-predicted
  budget; verify Kelvin (vary lead length → no shift).
- **Stage 4 — Real RTDs, two-point.** Ice bath (0 °C → R0) and a second known temperature vs
  a reference thermometer. *Gate:* both within budget.
- **Stage 5 — Noise & position independence (headline).** At fixed temperature, record noise
  on every channel. *Gate:* (a) per-channel noise at/below the resolution target, and (b)
  **no dependence on channel/position** — compare directly against the old series-chain data.
  This is the test the redesign exists to pass.
- **Stage 6 — Crosstalk.** Perturb one channel (warm one RTD); others must not move beyond
  noise. *Gate:* no measurable coupling.
- **Stage 7 — Thermal soak (validates the new accuracy term).** Soak for hours at fixed
  temperature and watch **C drift** — this directly measures the R_ref + relative-ADC-gain-
  tempco term and tests the "keep both ADCs thermally stable" assumption. *Gate:* drift
  within budget; if C drifts more than predicted, improve thermal coupling of the two ADCs or
  shorten the recal interval.
- **Stage 8 — CRD noise check (the source risk).** Confirm on hardware that CRD noise over a
  scan is below the floor — the one thing that, if it fails, forces swapping the CRD for a
  reference+op-amp source. The ratiometric readout stays either way.

Bench data → `test/data/` (committed). Each stage gets a report.

---

## Report format (SPICE and bench)

One markdown report per test/stage in `reports/sim/` or `reports/test/`, same skeleton:

```
# <Test/Stage> — <date> — <sim | bench>
## Objective        (what it proves; which acceptance criterion)
## Setup            (deck/instruments; T7 range + resolution index; ADS1115 PGA range; DUT)
## Method           (exact steps / command / sweep params)
## Results          (table: quantity | expected | measured | unit; plots)
## Pass / Fail      (criterion, then PASS/FAIL with margin)
## Anomalies & notes
## Next
```

After a test, record pass/fail and the report path in the session log under **Validation**. A
SPICE failure blocks the fab drop; a bench failure blocks sign-off on that rev and becomes a
new session objective.

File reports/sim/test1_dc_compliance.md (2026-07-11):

# Test 1 - DC operating point & CRD compliance — 2026-06-22 — sim

## Objective
Acceptance (a): the CRD keeps regulating (V across it > V_L) across the full Pt100 sweep at the worst-case low rail.

## Setup
Deck sim/netlists/test1_dc_compliance.cir; ngspice op sweep of Vrrtd 29-158 Ohm (100 K cryostat floor to +150 C) at rail = 5.0 V and 4.5 V; CRD = 100 uA || 5 MOhm.

## Method
Vcrd = v(rail)-v(top) over the sweep; take the minimum at the low rail and compare to V_L.

## Results
| quantity | expected | measured | unit |
|---|---|---|---|
| min V across CRD (rail 4.5 V) | > 2.0 | 4.383 | V |
| margin above V_L | > 0 | 2.383 | V |
| V_RTD span (Pt100) | 18-35 | 2.9-16.0 | mV |

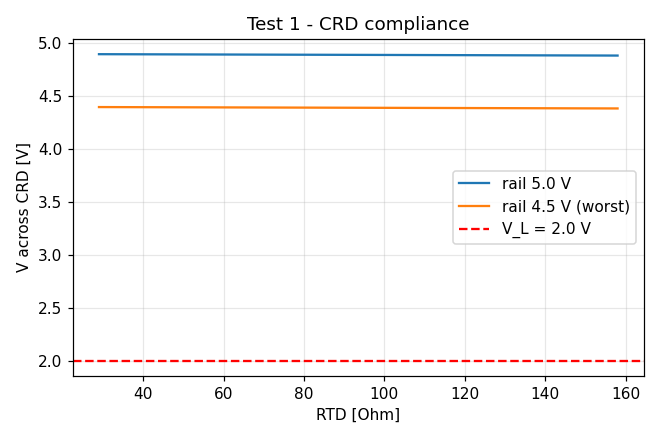
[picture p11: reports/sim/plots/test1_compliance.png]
compliance


## Pass / Fail
Criterion min Vcrd > V_L=2.0 V. **PASS** (margin 2.38 V).

## Next
Re-point at the exported KiCad netlist in Wave 3.

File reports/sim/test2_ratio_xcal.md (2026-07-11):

# Test 2 - Ratiometric + cross-cal correctness — 2026-06-22 — sim

## Objective
Acceptance (b): R_calc = C*V_RTD/V_ref recovers the swept RTD and is invariant to +/-10% CRD and R_ref perturbation.

## Setup
Deck test2_ratio_xcal.cir; Vrrtd 80-158 Ohm at five (kc,kref) corners.

## Method
CRD spread checked with the NOMINAL C (proves live current cancellation); R_ref spread checked with each corner's own cross-cal (proves the value is absorbed into C).

## Results
| case | applied C | max |R_calc-RTD|/RTD |
|---|---|---|
| CRD +/-10% | nominal (no recal) | 1.02e-08 |
| R_ref +/-10% | per-corner recal | 1.11e-08 |

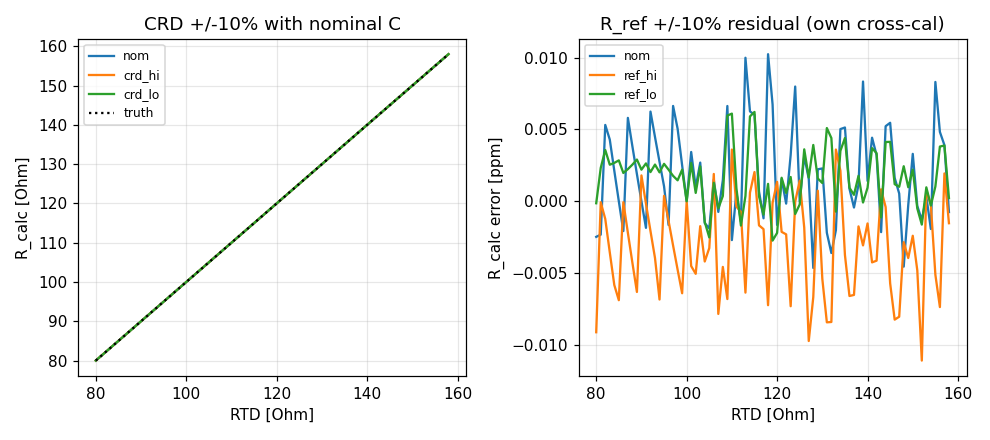
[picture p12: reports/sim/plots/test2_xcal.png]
xcal


## Pass / Fail
Criterion max error < 1e-06. **PASS** (CRD 1.0e-08, R_ref 1.1e-08 -> numerical floor).

## Next
Bench Stage 2/3 repeats this with real parts.

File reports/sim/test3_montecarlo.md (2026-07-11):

# Test 3 - Monte-Carlo accuracy -> degC error — 2026-06-22 — sim

## Objective
Acceptance (c): over board dT the accuracy stays within target, with the reference resistor NOT the limiting term (rev-F: 2 ppm/C R_ref; ADC gain tempco + offset drift set the residual).

## Setup
Deck test3_montecarlo.cir; N=2000 Gaussian samples; dT=10 C; sigmas R_ref/gain=2/10 ppm/C, offset=1 uV; cross-cal C verified = R_ref0 = 1000 Ohm.

## Method
Per sample: cross-cal at dt=0, then op at dt with sampled tempco/offset; fractional error -> Pt100 degC via x255.9.

## Results
| term | 1-sigma input | degC (1-sigma) |
|---|---|---|
| R_ref tempco | 2 ppm/C | 0.0051 |
| relative ADC gain tempco | 10 ppm/C | 0.0256 |
| V_RTD offset drift | 1 uV | 0.0256 |
| **analytic RSS** | | **0.0365** |
| **MC sigma (sim)** | | **0.0365** |
| MC 95th pct \|err\| | | 0.0710 |

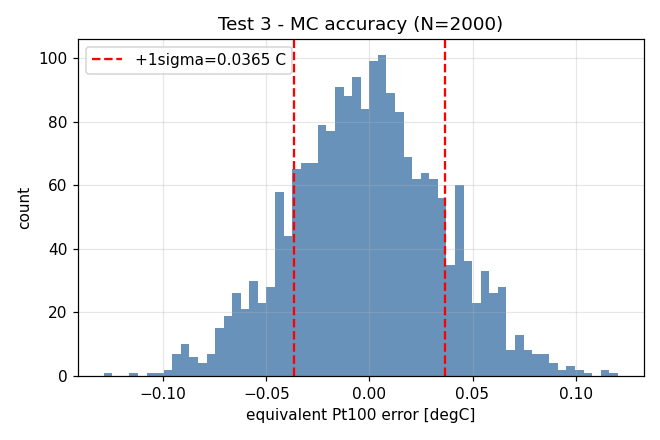
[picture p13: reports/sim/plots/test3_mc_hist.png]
hist


## Pass / Fail
Criterion sigma <= 0.05 C AND R_ref tempco not limiting. **PASS** (sigma=0.0365 C; R_ref term 0.0051 C <= gain 0.0256 / offset 0.0256 C).

## Anomalies & notes
Offset term scales as 1/V_RTD (~10 mV at 100 uA) and is now, with ADC gain tempco, the accuracy limiter between recals - the deliberate rev-F trade for ~6x lower cryostat self-heating. Mitigations: recal cadence, thermal stability of the T7, and tracking the T7 internal-GND channel for offset drift.

## Next
Inject real part tempco/offset specs; bench Stage 7 measures C drift.

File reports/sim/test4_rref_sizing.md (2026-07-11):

# Test 4 - R_ref sizing / no-clip vs ADS1115 range — 2026-06-22 — sim

## Objective
Acceptance: worst-case V_ref stays under the ADS1115 +/-0.256 V range with margin and good effective bits.

## Setup
Deck test4_rref_sizing.cir; R_ref=1.00 kOhm; sweep CRD scale kc 0.4-2.2.

## Method
V_ref = drop across R_ref (RTD-independent); evaluate at kc=2.10 (0.21 mA, S-101T guaranteed band max) and compare to 90% of full scale.

## Results
| quantity | expected | measured | unit |
|---|---|---|---|
| V_ref at band-max CRD (0.21 mA) | < 230 | 211.0 | mV |
| fraction of ADS FS | < 90 | 82.4 | % |
| effective bits used | high | 14.7 | bits |

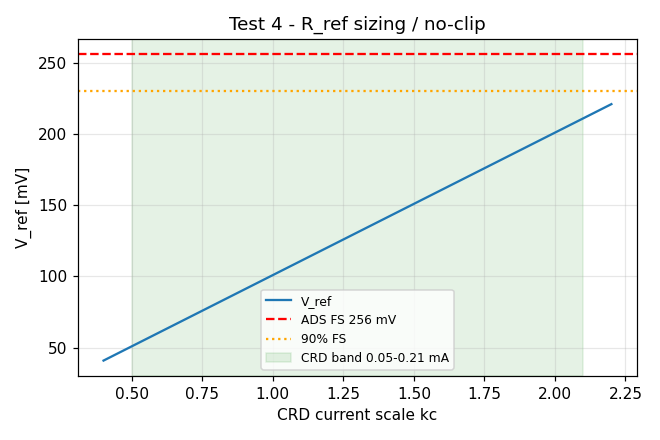
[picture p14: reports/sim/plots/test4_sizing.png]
sizing


## Pass / Fail
Criterion V_ref(band max) < 90% FS. **PASS** (82% FS).

## Next
Headroom is generous at 82% FS worst case; a low-band S-101T (0.05 mA) reads V_ref at ~20% FS - averaging covers the resolution loss.

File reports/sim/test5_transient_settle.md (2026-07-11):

# Test 5 - Sense-line RC settling vs mux dwell — 2026-06-22 — sim

## Objective
Acceptance: the 1 kOhm/0.1 uF sense filter settles to < 1/2 T7 LSB within the per-channel mux dwell.

## Setup
Deck test5_transient_settle.cir; CRD switched on at t=100 us; RF=1 kOhm, CF=0.1 uF; .tran to 1.2 ms.

## Method
Find the last time the filtered node is outside final +/- 1/2 LSB; compare that settle time to the mux dwell.

## Results
| quantity | expected | measured | unit |
|---|---|---|---|
| RC time constant | ~100 | 100 | us |
| settle to 1/2 LSB (1 uV) | < 5 | 0.97 | ms |
| mux dwell budget | - | 5 | ms |

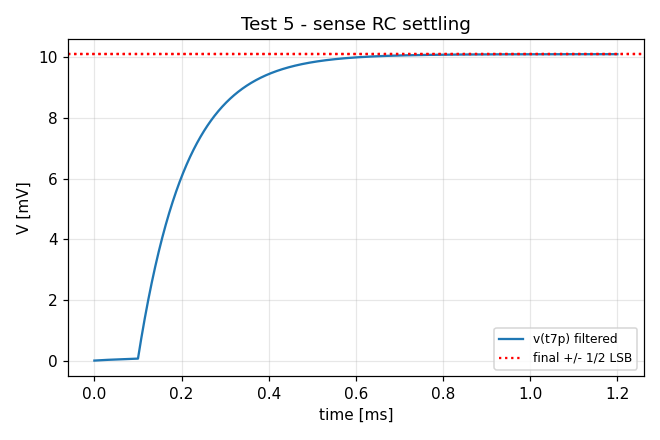
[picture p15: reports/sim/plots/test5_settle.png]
settle


## Pass / Fail
Criterion settle < dwell. **PASS** (settle 0.97 ms < 5 ms).

## Next
Confirm the chosen scan dwell on the T7 in Track C / bench.

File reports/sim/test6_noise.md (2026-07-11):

# Test 6 - Noise of the ratio — 2026-06-22 — sim

## Objective
Acceptance (d): ratio noise below the per-channel resolution target, with the CRD current-noise risk explicitly bounded.

## Setup
ngspice .noise -> Johnson PSD (V_ref 4.07, V_RTD 1.29 nV/rtHz); BW=10 Hz. T7=0.5 uV and ADS=5 uV RMS are ASSUMPTIONS (named in run_all.py) - the bench must confirm them.

## Method
RSS-combine each path's noise, divide by its signal (V_ref=201 mV, V_RTD=22.1 mV), RSS the two fractions, x255.9 -> degC. Only the Johnson terms are physically derived (and negligible); the ADCs dominate, so the PASS is CONDITIONAL on the assumed ADC noise. We therefore back-solve the max-allowable T7 noise. CRD noise is common to both reads -> CANCELS in the ratio under simultaneous sampling; its bound is the i_n that would reach target if sampling were NOT simultaneous.

## Results
| source | contribution [degC RMS] | note |
|---|---|---|
| Johnson R_ref (ngspice) | 0.0329 m | physical |
| Johnson RTD (ngspice) | 0.1042 m | physical |
| ADS1115 V_ref | 12.7933 m | **assumed 5 uV** |
| T7 V_RTD | 12.7933 m | **assumed 0.5 uV** |
| **total** | **18.093 m** | vs 20 m target |
| **max-allowable T7 noise** | | **0.60 uV RMS** (back-solved) |
| CRD current-noise bound (worst case) | | 0.74 nA/rtHz |

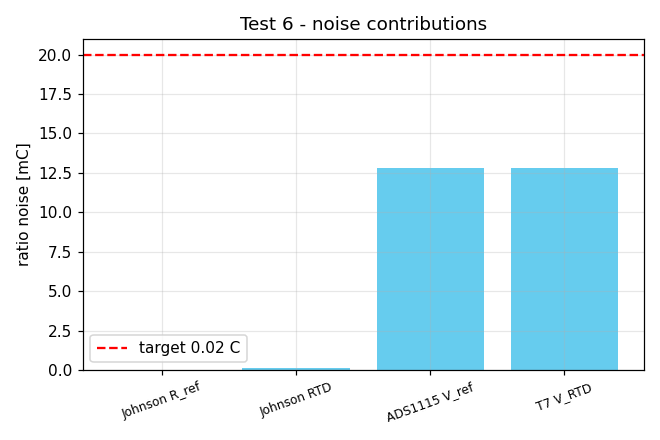
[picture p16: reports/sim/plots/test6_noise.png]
noise


## Pass / Fail
Conditional criterion: total < 20 mdegC **iff** T7 <= 0.60 uV and ADS <= 5 uV RMS. At the assumed 0.5/5 uV: **PASS** (18.1 mdegC, 1.1x margin). CRD bound 0.7 nA/rtHz worst-case (~0 if simultaneous).

## Anomalies & notes
PASS rides on assumed ADC noise; the physically-derived (Johnson) terms are ~0.05 mdegC. The number the bench (Track C, Wave 3 Stage 5) must beat: **T7 <= 0.60 uV RMS** (at ADS 5 uV, BW 10 Hz). The small V_RTD (~10 mV at 100 uA) is why the T7 path dominates.

## Next
Bench Stage 5 (noise/position) measures real T7/ADS noise; Stage 8 the CRD.

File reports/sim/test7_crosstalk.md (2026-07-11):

# Test 7 - Shared-ground crosstalk — 2026-06-22 — sim

## Objective
Acceptance: coupling between channels sharing a finite star-ground return stays below the noise floor; sets max ground R.

## Setup
Deck test7_crosstalk.cir; two unit cells share RG (sg->gnd) at RG = 0.01/0.1/1/10 Ohm. ADC CMRR: T7 90 dB, ADS1115 105 dB. Aggressor CRD swept over its guaranteed band (kca 0.5-2.1, dI_A ~ 160 uA); victim at 100 Ohm.

## Method
The aggressor current sets the shared-return common mode v(sg)=(I_A+I_B)*RG at the victim's inputs; the differential readout rejects it to first order, the residual leaks via finite ADC CMRR. Cross-cal the victim, then take its recovered-R swing as the aggressor current spans its band -> degC. (Note: the *ratio* metric cancels the channel current, so this coupling is genuinely the CMRR/shared-return path, not a metric artifact.)

## Results
| star-ground R [Ohm] | victim coupling [degC] |
|---|---|
| 0.01 | 2.56e-06 |
| 0.1 | 1.28e-05 |
| 1 | 1.28e-04 |
| 10 | 1.26e-03 |
| **at 0.1 Ohm budget** | **1.26e-05** |
| max RG meeting 0.02 C target | 158.9 Ohm |

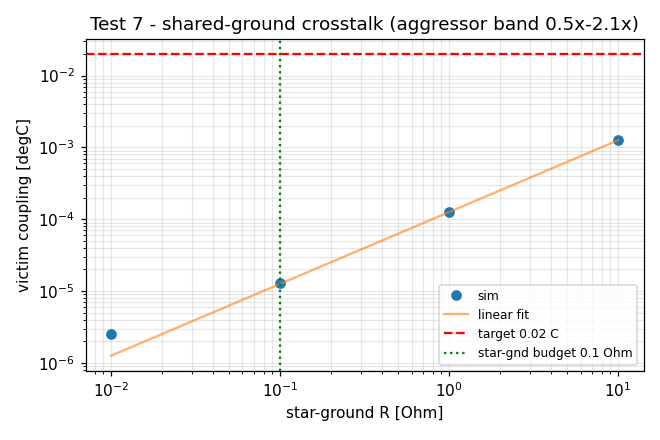
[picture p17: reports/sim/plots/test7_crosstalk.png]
crosstalk


## Pass / Fail
Criterion coupling < 0.02 C at the 0.1 Ohm budget. **PASS** (1.3e-05 C; linear at 1.3e-04 C/Ohm -> max RG 159 Ohm).

## Anomalies & notes
Coupling scales linearly with star-ground R, as expected for dI_A*RG/(CMRR*V_RTD). It is small because current-source isolation keeps dI_A modest and Kelvin + good CMRR reject the rest - so crosstalk is NOT the binding constraint on RG (noise/layout are), but it is now actually measured, not zero.

## Next
Bench Stage 6 perturbs one channel (warm an RTD / toggle current) and checks the others against this RG-dependent bound.

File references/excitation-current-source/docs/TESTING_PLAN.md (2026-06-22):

# TESTING_PLAN.md

Two-part verification for the REF200 RTD board, plus a shared report format.

- **Part 1 — SPICE (Claude Code runs):** prove the circuit is correct and quantify the
  accuracy/noise budget *before* fabrication.
- **Part 2 — Bench (Lucas runs):** staged bring-up with go/no-go gates, ending in the
  measurement that actually matters — position-independent, quiet readings.

Acceptance criteria are tied to the original problem: the board must (a) deliver a known,
stable per-channel current, (b) recover R to an accuracy set by the reference resistor,
not the REF200, and (c) show **no channel/position dependence** in the noise — the failure
mode of the old series chain.

---

## Part 1 — SPICE verification (ngspice, batch)

### Model strategy

- Look for a TI SPICE/PSpice model for the REF200 (product page). If one exists, place it
  in `sim/models/` and use it.
- If not, model each 100 µA section as an **ideal DC current source in parallel with a
  finite output resistance** (datasheet output impedance 20–100 MΩ; use ~50 MΩ). Parallel
  two for the 200 µA mode. For noise work, add an explicit current-noise source calibrated
  to the datasheet (1 nA p-p over 0.1–10 Hz; 20 pA/√Hz at 10 kHz) since an ideal source is
  noiseless in `.noise`.
- RTD = a resistor swept across its operating range (Pt100: ~80–157 Ω; Pt1000: ~800–1570 Ω).
- R_ref = the chosen precision value; vary it for tolerance/tempco studies.
- Run headless: `ngspice -b deck.cir -o reports/sim/<test>.log` and parse the output; have
  a python script in `sim/scripts/` produce plots into `reports/sim/`.

### Test cases (each → a deck in `sim/netlists/`, a result + report in `reports/sim/`)

1. **DC operating point & compliance margin.** Sweep RTD across its range at nominal and
   worst-case supply. *Pass:* voltage across each REF200 source stays ≥ 2.5 V (target
   ≥ 3 V margin) at the highest RTD resistance and lowest supply.
2. **Ratiometric correctness (sanity).** Sweep RTD; compute `R_calc = R_ref·V_RTD/V_ref`.
   *Pass:* `R_calc` equals the swept RTD value to within numerical error — confirms the
   topology and that the result is independent of the source value.
3. **Accuracy / Monte Carlo (the key deliverable).** Vary R_ref by its tolerance and over
   the expected board ΔT (tempco), include source-current variation and an assumed ADC
   offset/gain. Propagate to an **equivalent temperature error in °C** for the chosen RTD.
   *Pass:* total error dominated by R_ref, within the target budget (for 0.01 % / 10 ppm
   over ~10 °C this should land well under ±0.1 °C from the reference resistor; state the
   computed number).
4. **Compliance corner.** Max RTD R + min supply + tolerances. *Pass:* still in compliance.
5. **Transient — sense RC settling.** Step the sense node and measure settling of the
   ~1 kΩ/0.1 µF filter. *Pass:* settles to < ½ ADC LSB within the planned T7 mux dwell.
   This sizes the filter R/C and the scan rate together (ties to the "mux settling" risk).
6. **Noise (`.noise`).** Sum REF200 current-noise (×R) and Johnson noise of R_ref+RTD,
   band-limited by the RC filter, referred to the ADC input. *Pass:* total excitation +
   passive-chain noise is **below the T7 ADC noise floor** — i.e. the excitation is not
   the limiter (expected: ~100 nV-level vs mV signals). This confirms the architecture
   targets the real problem (CMRR/series stacking) without introducing a new noise source.
7. **Crosstalk (optional but recommended).** Model two channels sharing a finite
   star-ground return impedance; perturb one channel's current. *Pass:* coupling into the
   other channel's reading is below the noise floor for the planned ground resistance —
   use it to set the acceptable star-ground trace resistance.

Each test writes a report (next section) with measured-vs-expected and an explicit
pass/fail against its criterion. Failures block fabrication.

---

## Part 2 — Bench verification (real board)

Staged bring-up. **Each stage is a go/no-go gate; do not proceed past a failure.** Probe
the test points added per `BOARD_DEV_CHECKLIST.md`. Handle the REF200 with ESD precautions
(it is only ±750 V CDM rated) — wrist strap, grounded mat.

- **Stage 0 — Power off, inspection.** Visual check; DMM continuity for shorts on the rail
  and between force/sense nets; confirm no solder bridges on the REF200. *Gate:* no shorts.
- **Stage 1 — Power tree.** Bring up the LDO with the REF200 **not yet in circuit** (or
  outputs open). *Gate:* clean +5 V (or +3.3 V) within tolerance, low ripple.
- **Stage 2 — Current verification & per-channel calibration.** With a known precision
  resistor (or DMM in current mode) at each channel output, measure the actual delivered
  current. Record each channel's value — **this is the calibration constant** for the
  calibrated-current measurement mode. *Gate:* each channel within REF200 spec and stable.
- **Stage 3 — Ratiometric accuracy (substitution).** Replace RTDs with precision resistors
  or a decade box across the RTD range. Read V_ref and V_RTD on the T7; compute
  `R_ref·V_RTD/V_ref`. *Gate:* recovered R matches the known resistor across the range,
  within the SPICE-predicted budget.
- **Stage 4 — Compliance headroom.** At the largest resistance, confirm the channel still
  regulates (voltage doesn't collapse). *Gate:* in compliance.
- **Stage 5 — Real RTDs, two-point.** Connect the actual 4-wire RTDs. Ice bath (0 °C → R0)
  and a second known temperature against a reference thermometer. *Gate:* both points
  within budget; Kelvin sensing confirmed (vary lead length and see no shift).
- **Stage 6 — Noise & position independence (the headline test).** At a fixed, stable
  temperature, record noise on every channel. *Gate:* (a) per-channel noise at or below
  the T7 + Johnson floor, and (b) **no dependence on channel/position** — directly compare
  against the old series-chain data where noise grew up the chain. This is the test the
  whole redesign exists to pass.
- **Stage 7 — Crosstalk.** Perturb one channel (e.g. warm one RTD); confirm the others
  don't move beyond noise. *Gate:* no measurable cross-coupling.
- **Stage 8 — Thermal soak / drift.** Log all channels for hours at fixed temperature.
  *Gate:* drift within budget; confirm R_ref tempco dominates as predicted (not the
  REF200, not grounding).

Bench data lands in `test/data/` (committed — it can't be regenerated). Each stage gets a
report.

---

## Report format (both SPICE and bench)

One markdown report per test/stage in `reports/sim/` or `reports/test/`, using the same
skeleton so they're comparable:

```
# <Test/Stage name> — <date> — <sim | bench>

## Objective
<what this test proves, and which acceptance criterion it maps to>

## Setup
<deck file / instruments, T7 config (range, resolution index), DUT, conditions>

## Method
<exact steps / command run / sweep parameters>

## Results
<table: quantity | expected | measured | unit>
<plots: link to figure files>

## Pass / Fail
<criterion stated, then PASS or FAIL with the margin>

## Anomalies & notes
<anything unexpected; deviations from prediction>

## Next
<follow-up action, if any>
```

After running a test, Claude Code records the pass/fail and report path in the session log
under **Validation**. A SPICE failure blocks the fab drop; a bench failure blocks sign-off
on that rev and feeds back into a new session objective.

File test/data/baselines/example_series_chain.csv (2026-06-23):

iso_time | t_rel_s | stage | channel | ads_addr | v_ref | v_rtd | ratio | c_const | r_calc | t_calc | r_known | note
2026-06-22T17:56:22.077+00:00 | 0.002185 | baseline_series_chain | 0 | 0x48 | 0.2002021484375 | 0.02285996591182078 | 0.11418441855012014 | 910.0 | 103.90782088060932 | 10.013590533844202 |  | synthetic series-chain
2026-06-22T17:56:22.077+00:00 | 0.002185 | baseline_series_chain | 1 | 0x48 | 0.19744580078125 | 0.025900412801973936 | 0.13117732916826616 | 910.0 | 119.3713695431222 | 49.93311293578513 |  | synthetic series-chain
2026-06-22T17:56:22.077+00:00 | 0.002185 | baseline_series_chain | 2 | 0x49 | 0.19563671875000002 | 0.028974671503362876 | 0.1481044646858394 | 910.0 | 134.77506286411386 | 90.17911001026879 |  | synthetic series-chain
2026-06-22T17:56:22.077+00:00 | 0.002185 | baseline_series_chain | 0 | 0x48 | 0.20021289062499997 | 0.022852622993566357 | 0.1141416165673841 | 910.0 | 103.86887107631954 | 9.913637023292338 |  | synthetic series-chain
2026-06-22T17:56:22.077+00:00 | 0.002185 | baseline_series_chain | 1 | 0x48 | 0.197447265625 | 0.025908442357985 | 0.1312170228135313 | 910.0 | 119.40749076031346 | 50.026920315708 |  | synthetic series-chain
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

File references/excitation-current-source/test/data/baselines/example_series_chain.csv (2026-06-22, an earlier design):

iso_time | t_rel_s | stage | channel | v_ref | v_rtd | r_calc | t_calc | r_known | i_meas_a | note
2026-06-19T06:32:34.323+00:00 | 0.002 | baseline_series_chain | 0 |  | 0.00960971232120046 | 96.09517233568022 | -9.976292345856669 |  |  | synthetic series-chain
2026-06-19T06:32:34.323+00:00 | 0.002 | baseline_series_chain | 1 |  | 0.011919010771280545 | 119.35425032238275 | 49.888654967084754 |  |  | synthetic series-chain
2026-06-19T06:32:34.323+00:00 | 0.002 | baseline_series_chain | 2 |  | 0.01418917578044122 | 142.25010927082934 | 109.88782809248453 |  |  | synthetic series-chain
2026-06-19T06:32:34.323+00:00 | 0.002 | baseline_series_chain | 0 |  | 0.009613467393634662 | 96.13068037486681 | -9.885708544113614 |  |  | synthetic series-chain
2026-06-19T06:32:34.323+00:00 | 0.002 | baseline_series_chain | 1 |  | 0.0119213186514185 | 119.39963783865606 | 50.00652592776489 |  |  | synthetic series-chain
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

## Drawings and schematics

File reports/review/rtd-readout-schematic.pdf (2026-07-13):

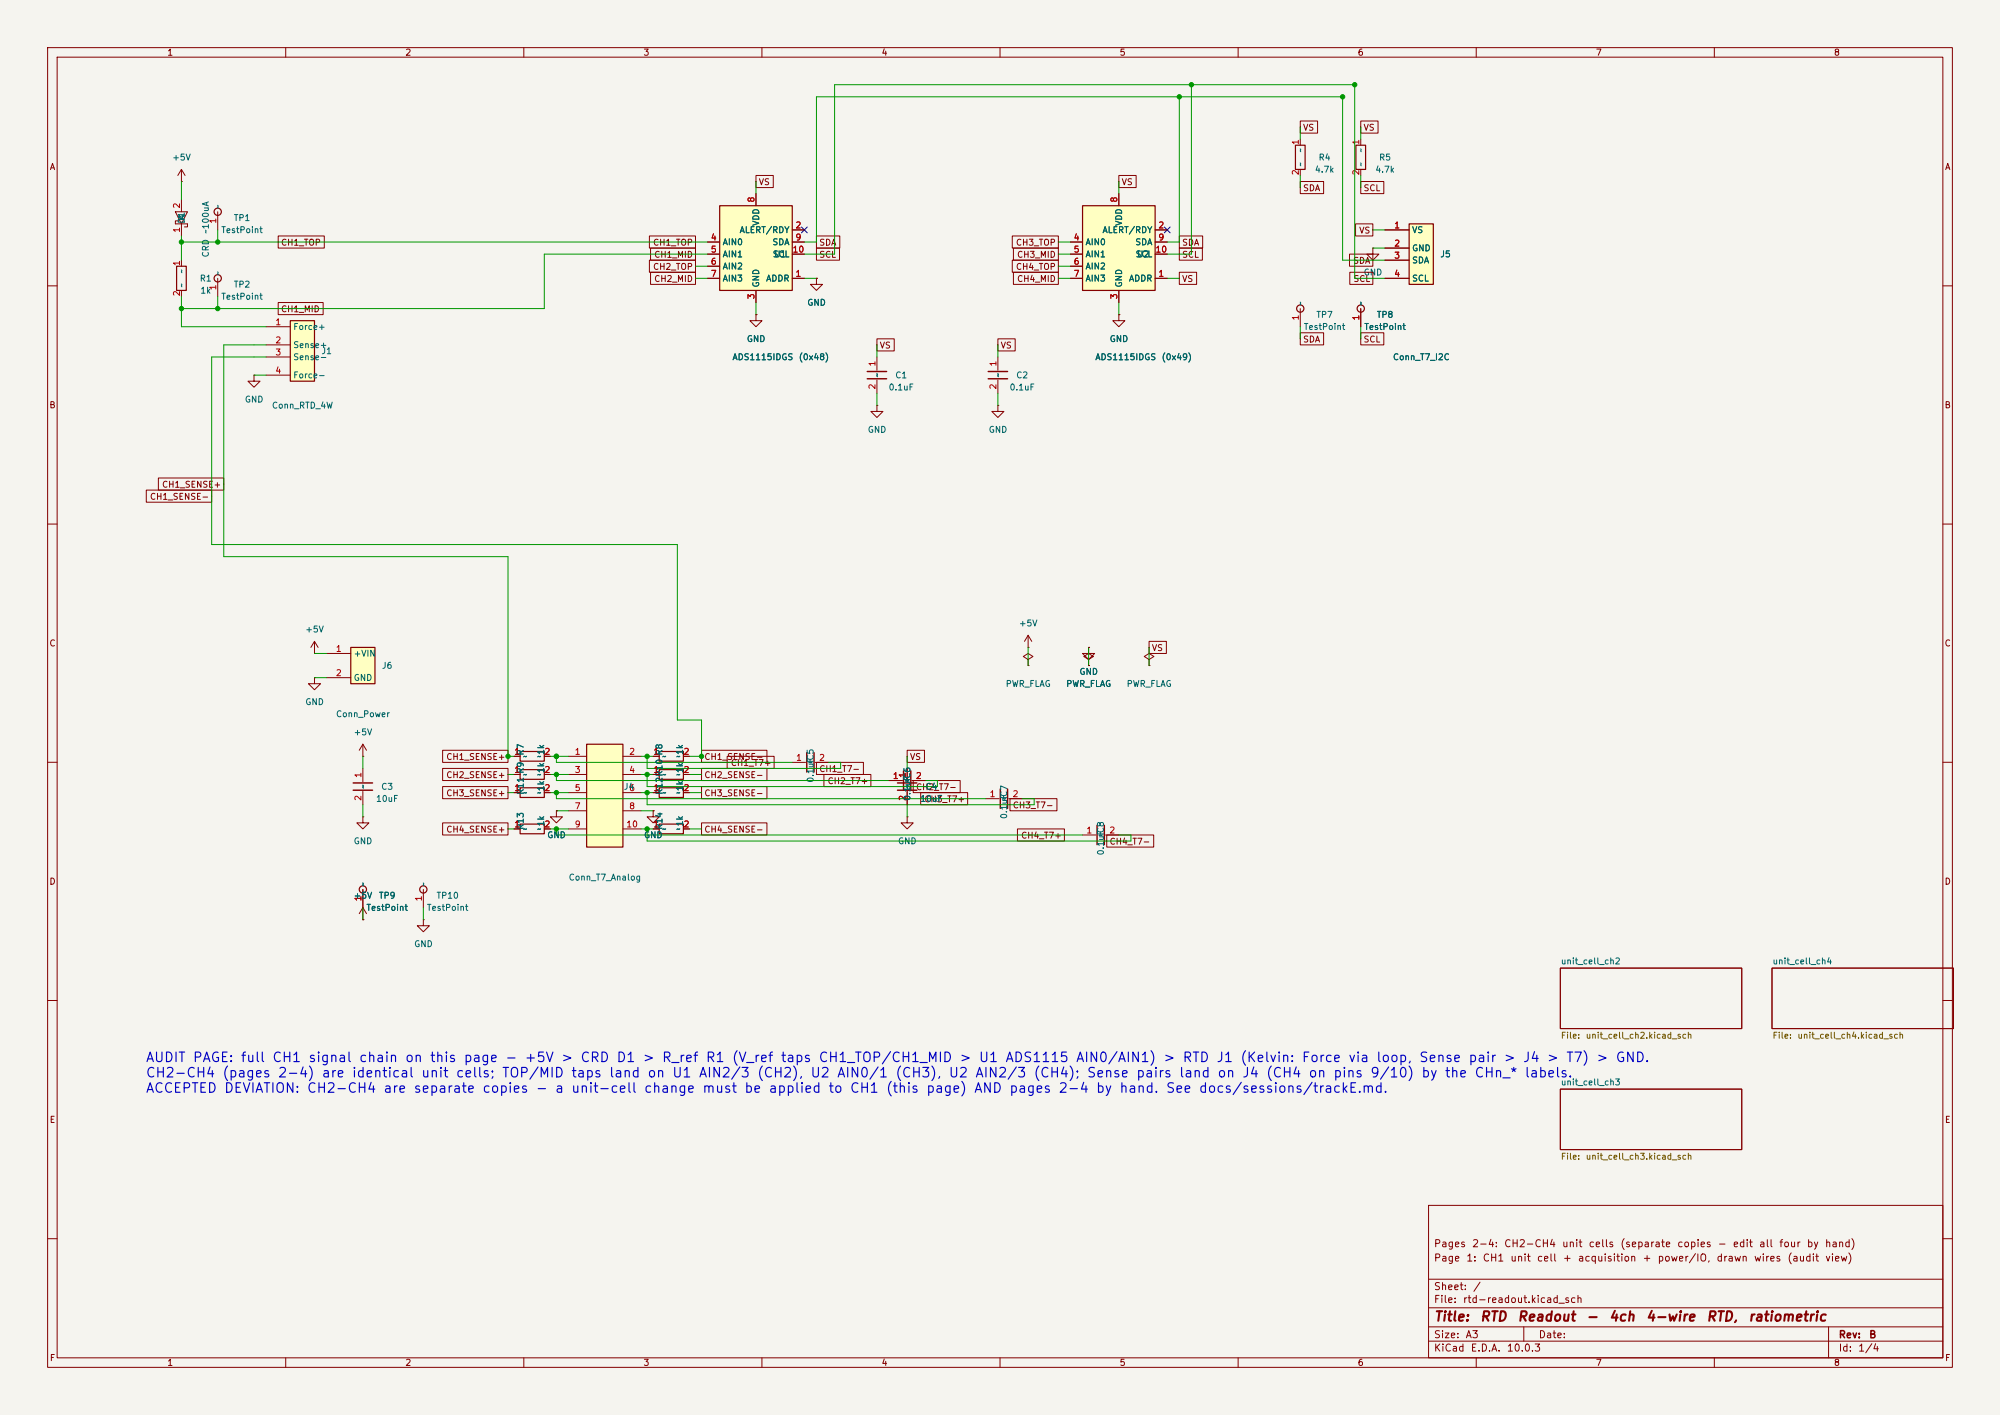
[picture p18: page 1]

SDA AUDIT PAGE: full CH1 signal chain on this page - +5V > CRD D1 > R_ref R1 (V_ref taps CH1_TOP/CH1_MID > U1 ADS1115 AIN0/AIN1) > RTD J1 (Kelvin: Force via loop, Sense pair > J4 > T7) > GND.

ACCEPTED DEVIATION: CH2-CH4 are separate copies - a unit-cell change must be applied to CH1 (this page) AND pages 2-4 by hand. See docs/sessions/trackE.md. TP9

CH2-CH4 (pages 2-4) are identical unit cells; TOP/MID taps land on U1 AIN2/3 (CH2), U2 AIN0/1 (CH3), U2 AIN2/3 (CH4); Sense pairs land on J4 (CH4 on pins 9/10) by the CHn_* labels.

Pages 2-4: CH2-CH4 unit cells (separate copies - edit all four by hand)
Page 1: CH1 unit cell + acquisition + power/IO, drawn wires (audit view)

Sheet: /
File: rtd-readout.kicad_sch
Title: RTD Readout - 4ch 4-wire RTD, ratiometric

Size: A3 | Rev: B
KiCad E.D.A. 10.0.3 | Id: 1/4 | F Date:

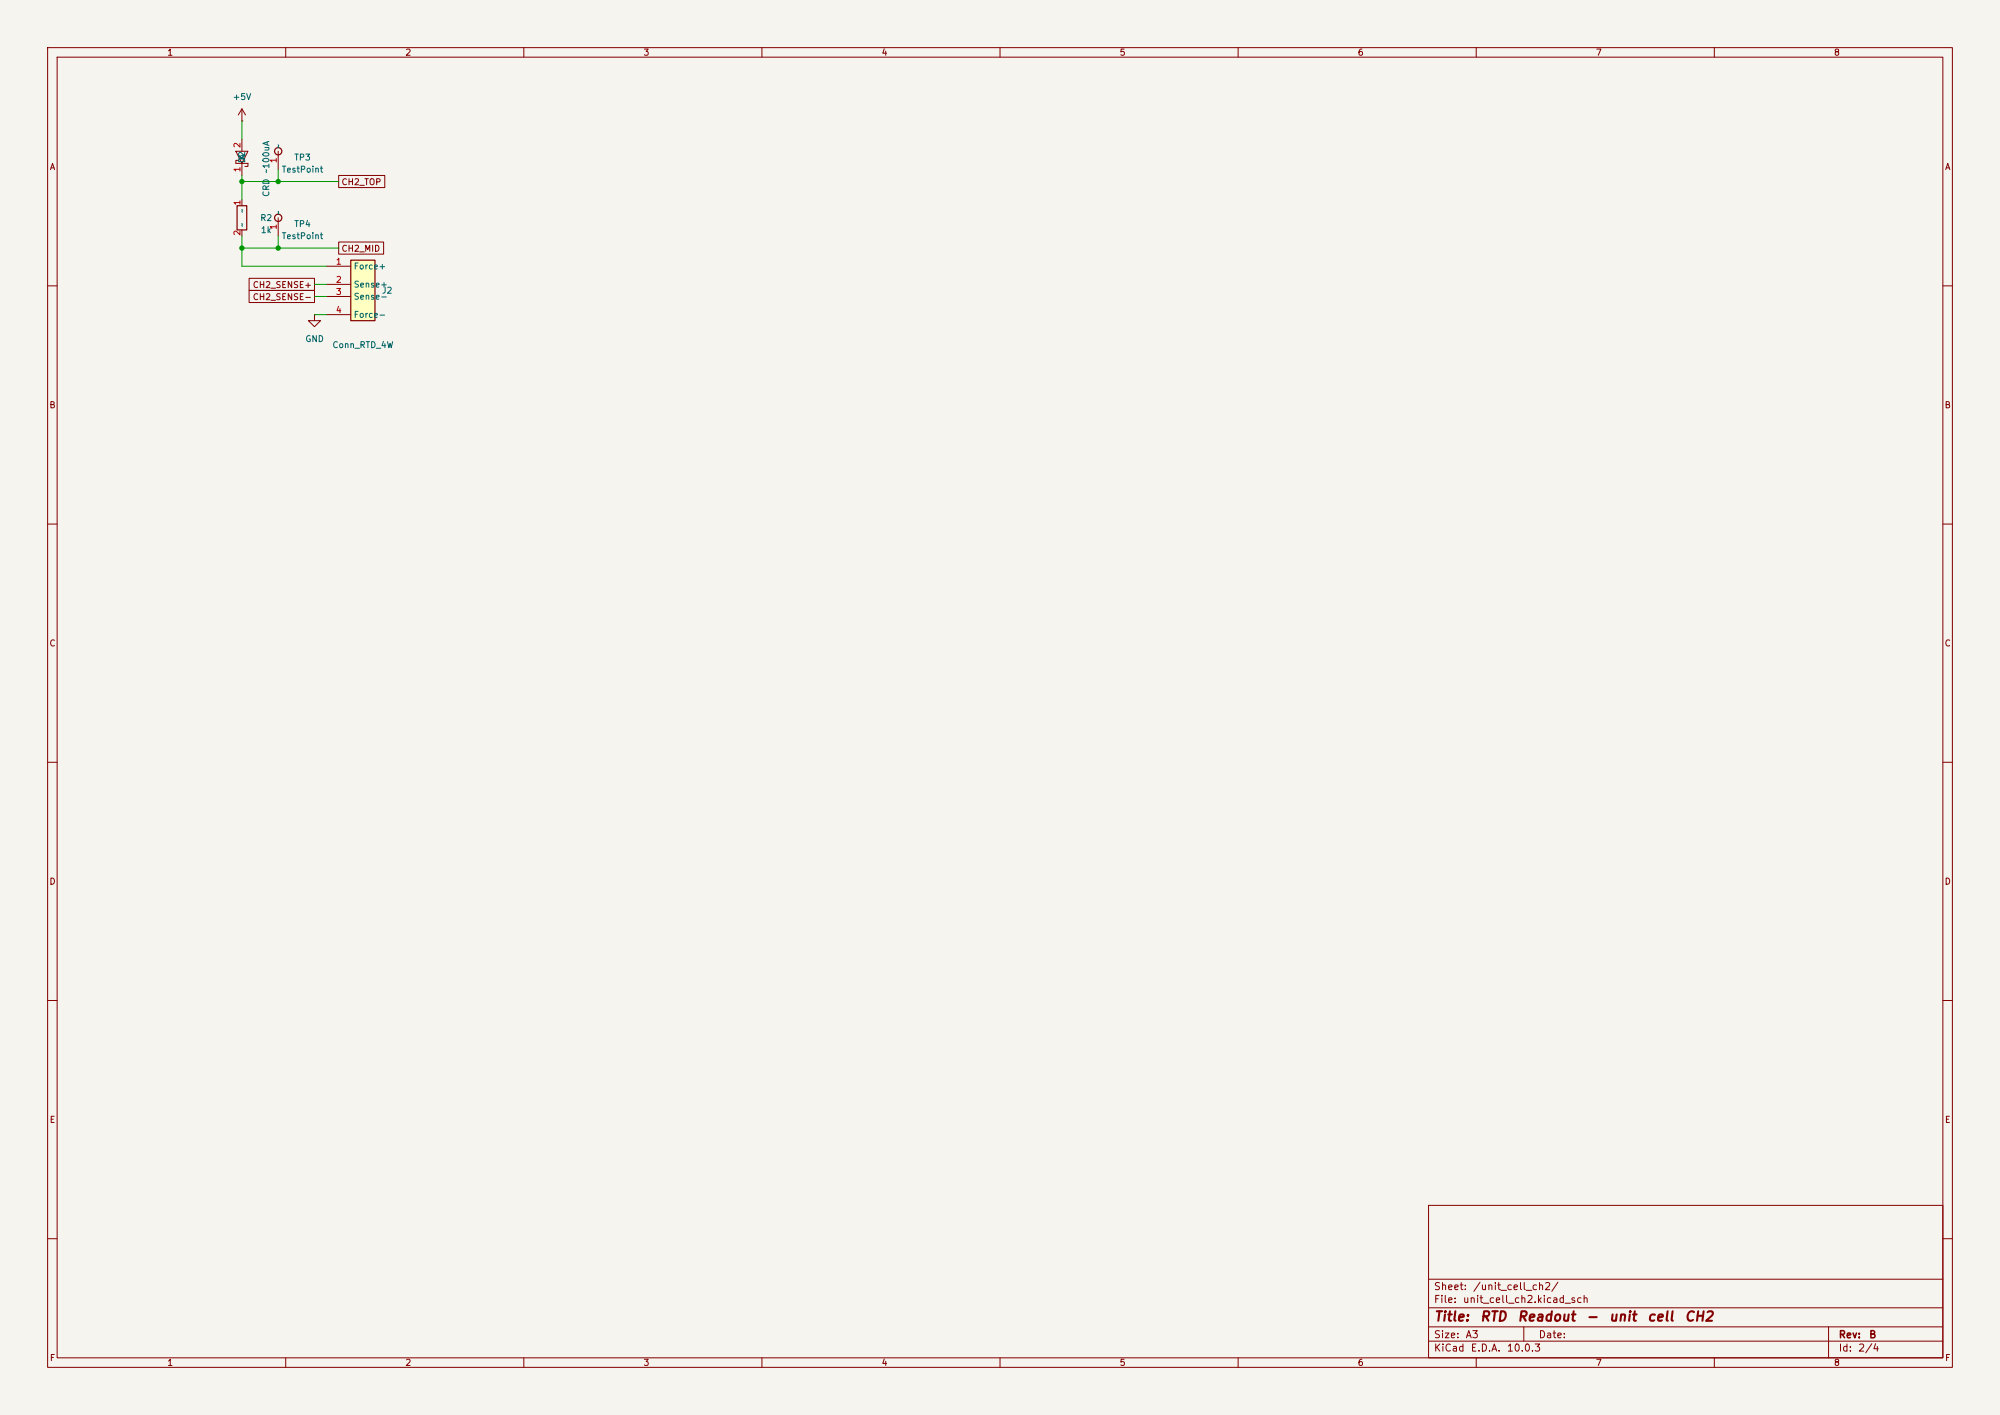
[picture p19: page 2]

Sheet: /unit_cell_ch2/
File: unit_cell_ch2.kicad_sch
Title: RTD Readout - unit cell CH2

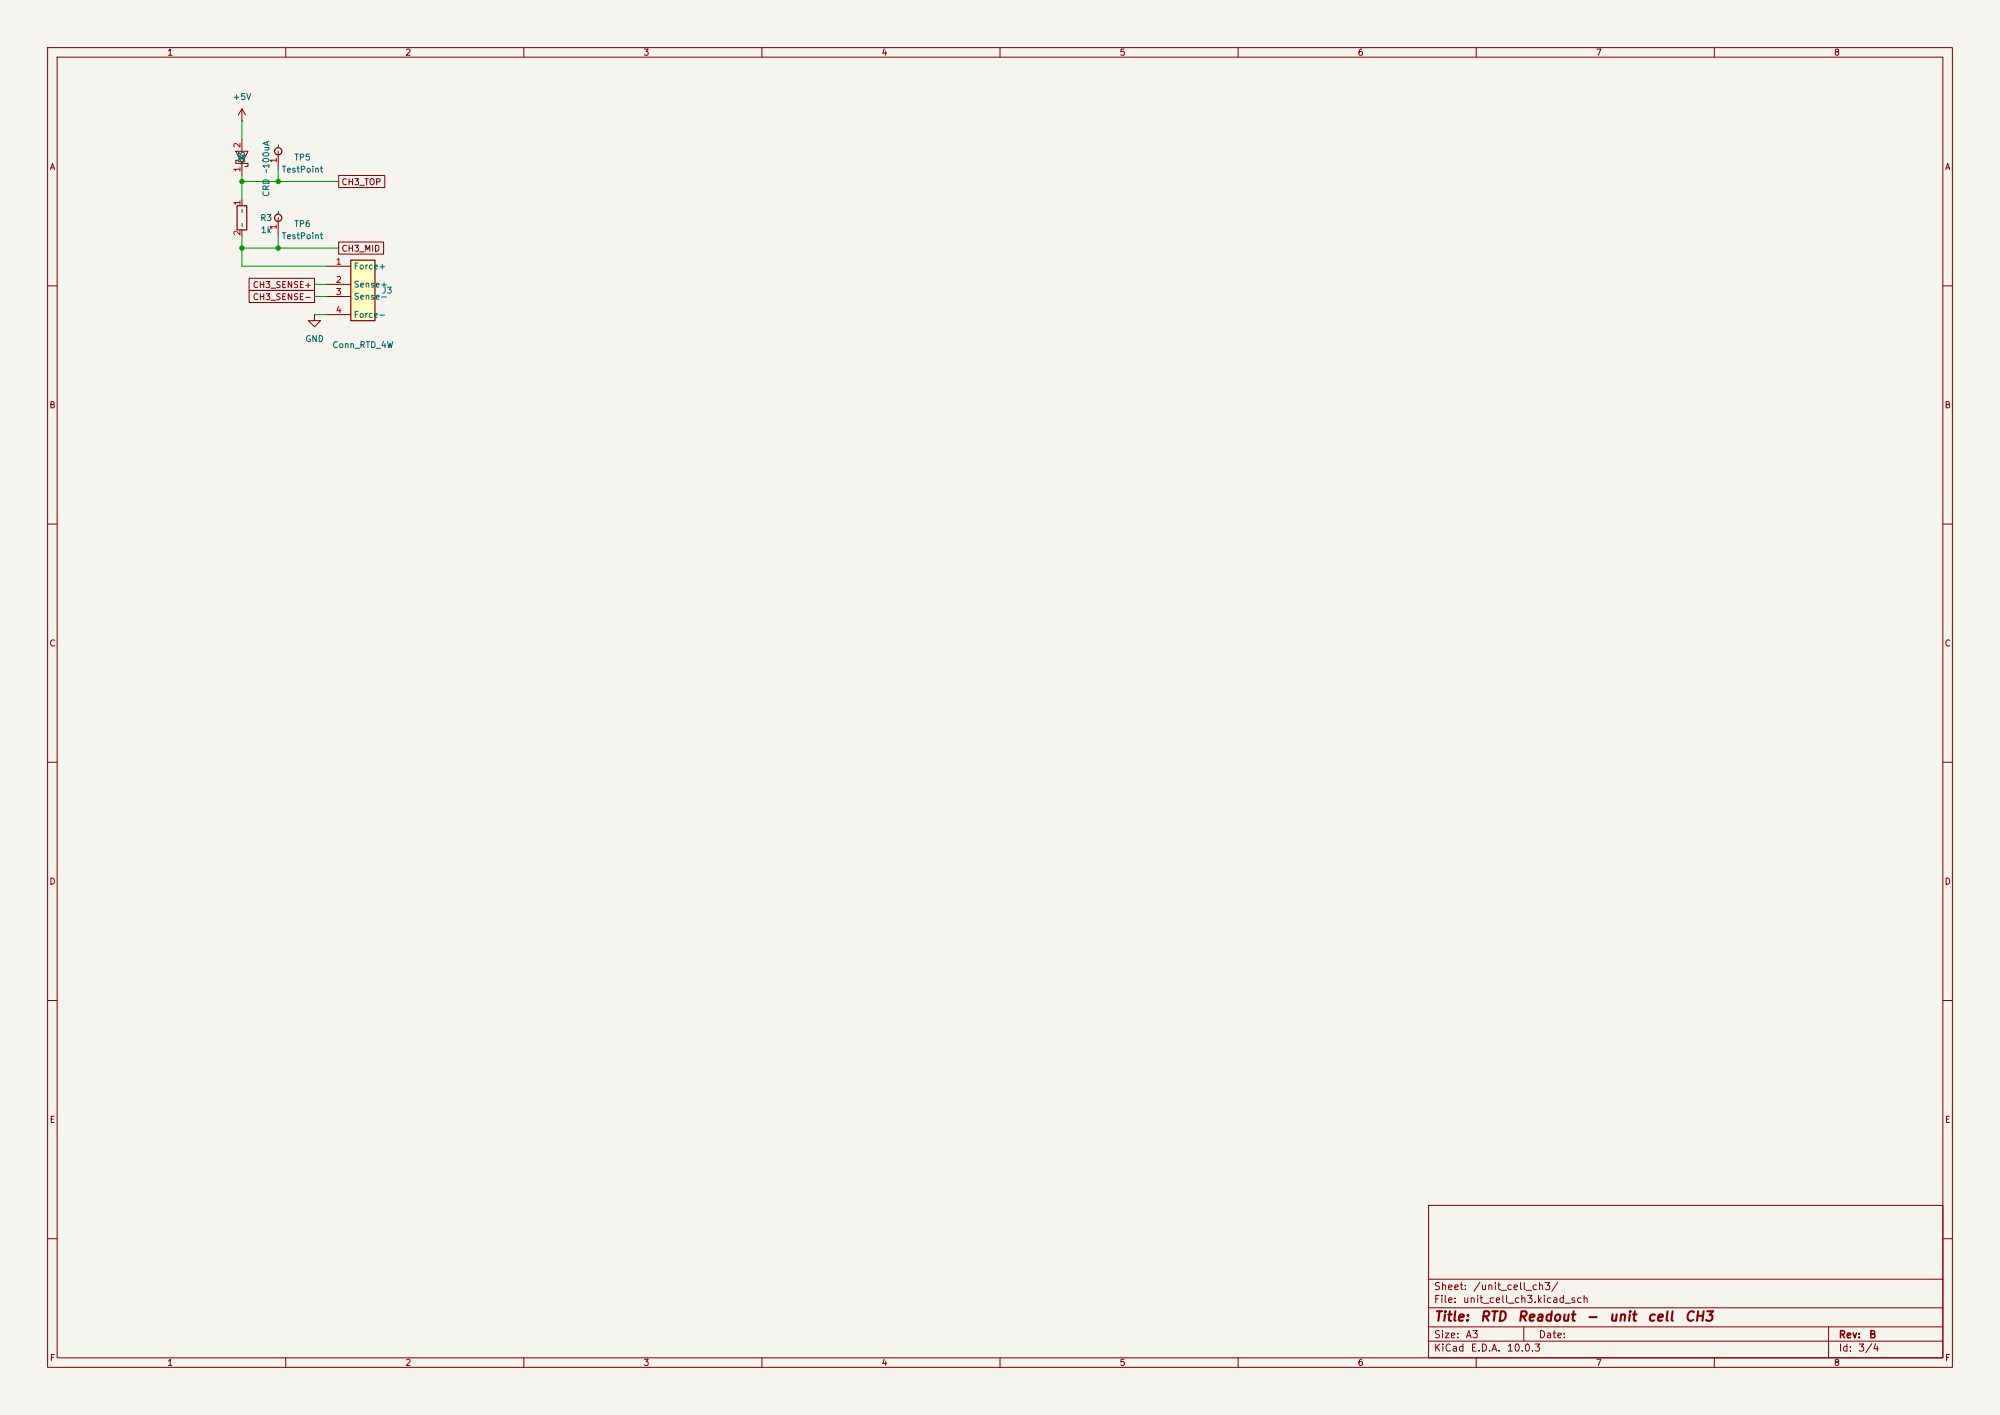
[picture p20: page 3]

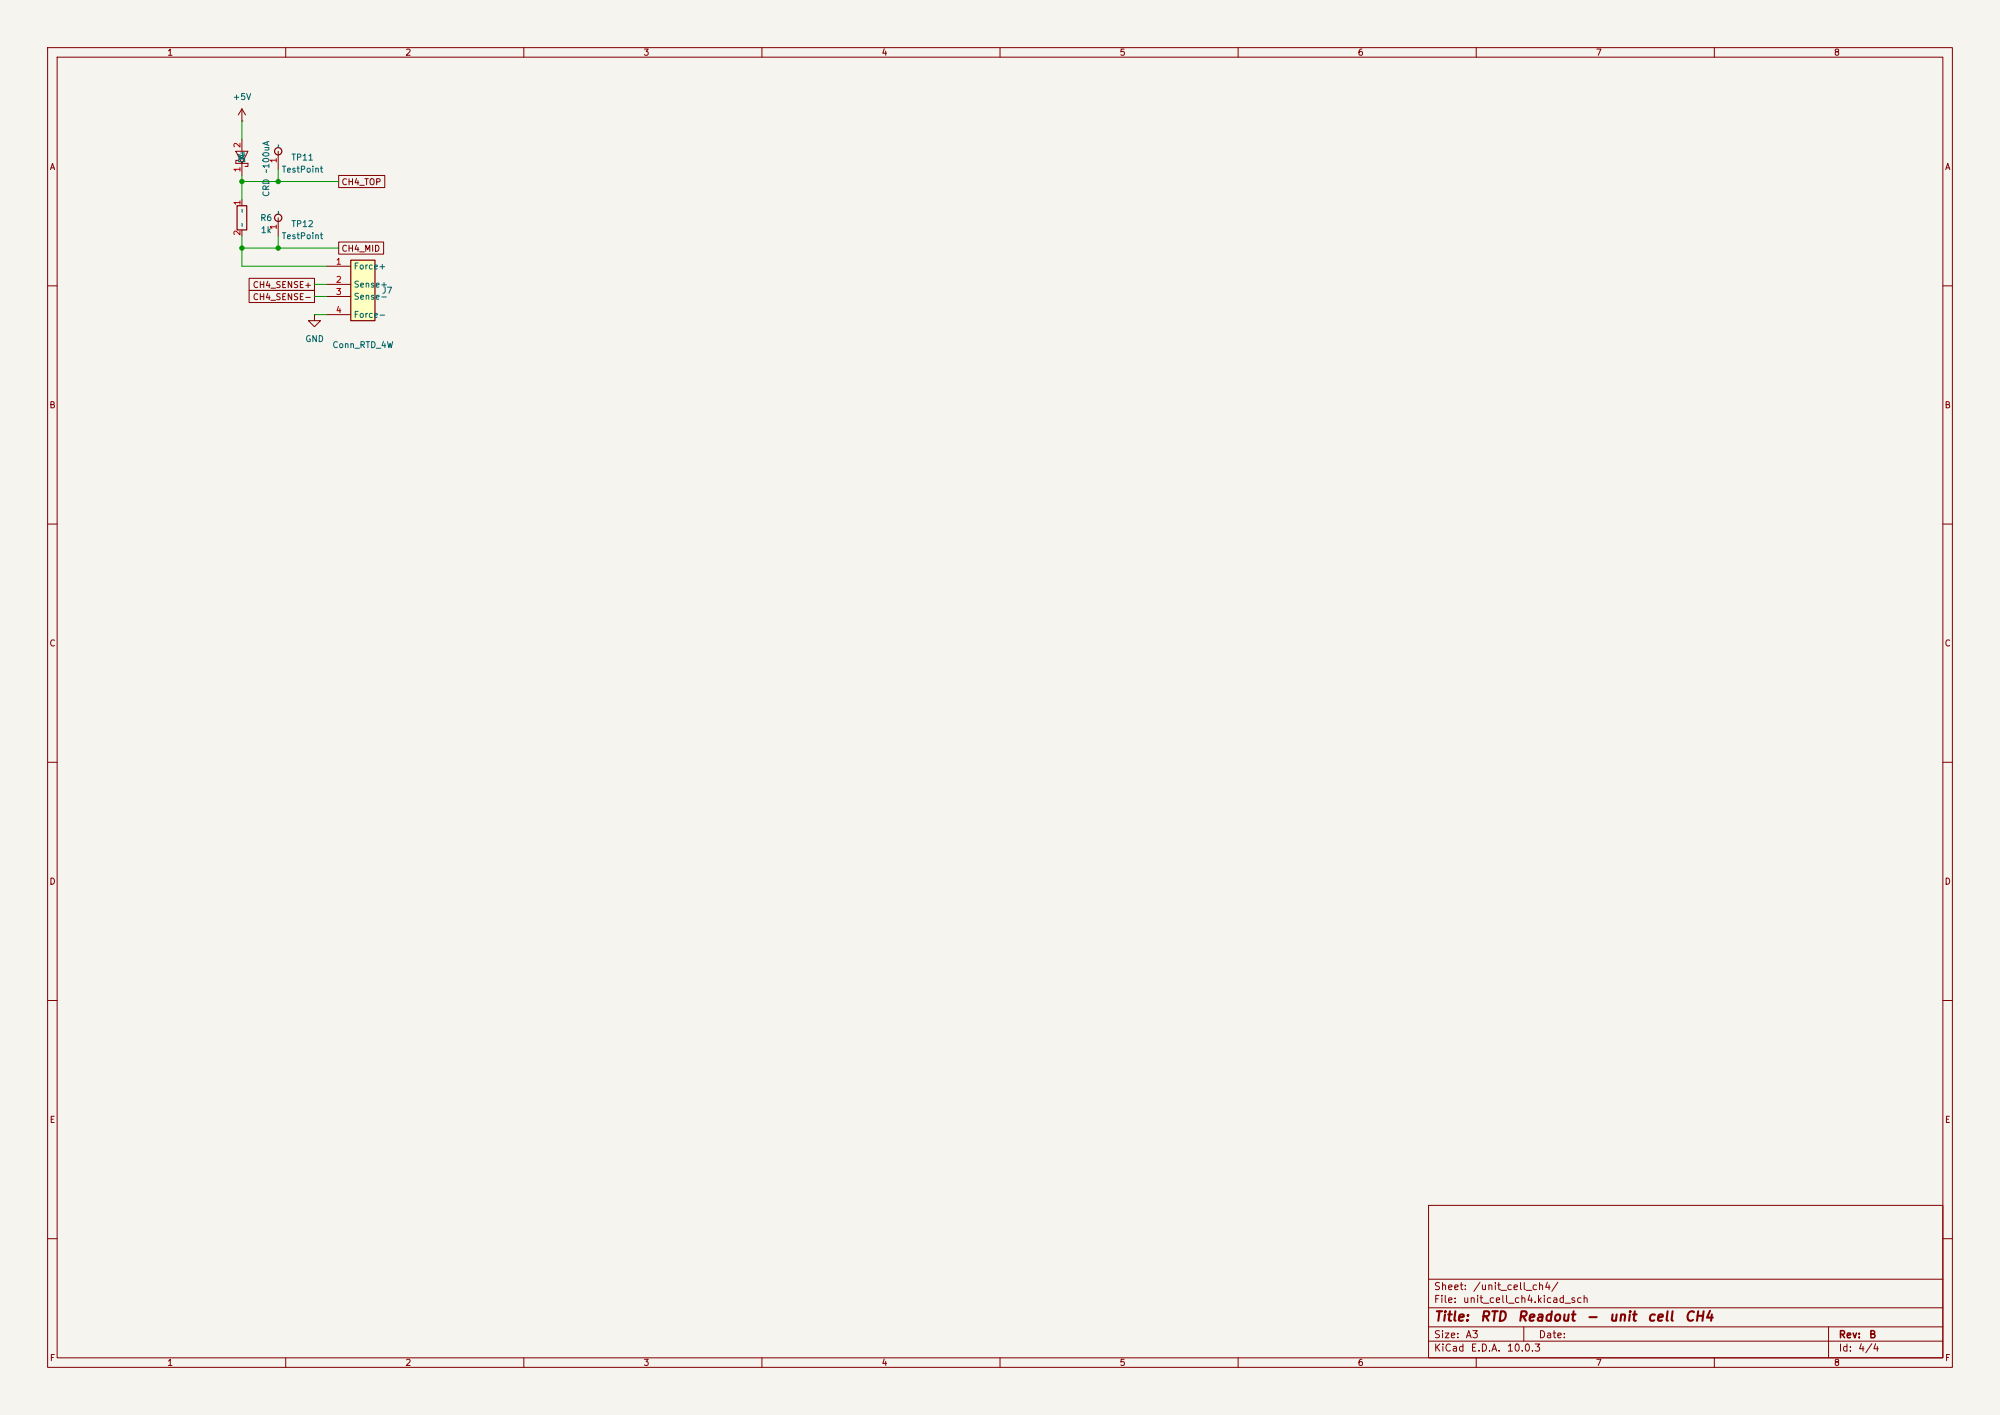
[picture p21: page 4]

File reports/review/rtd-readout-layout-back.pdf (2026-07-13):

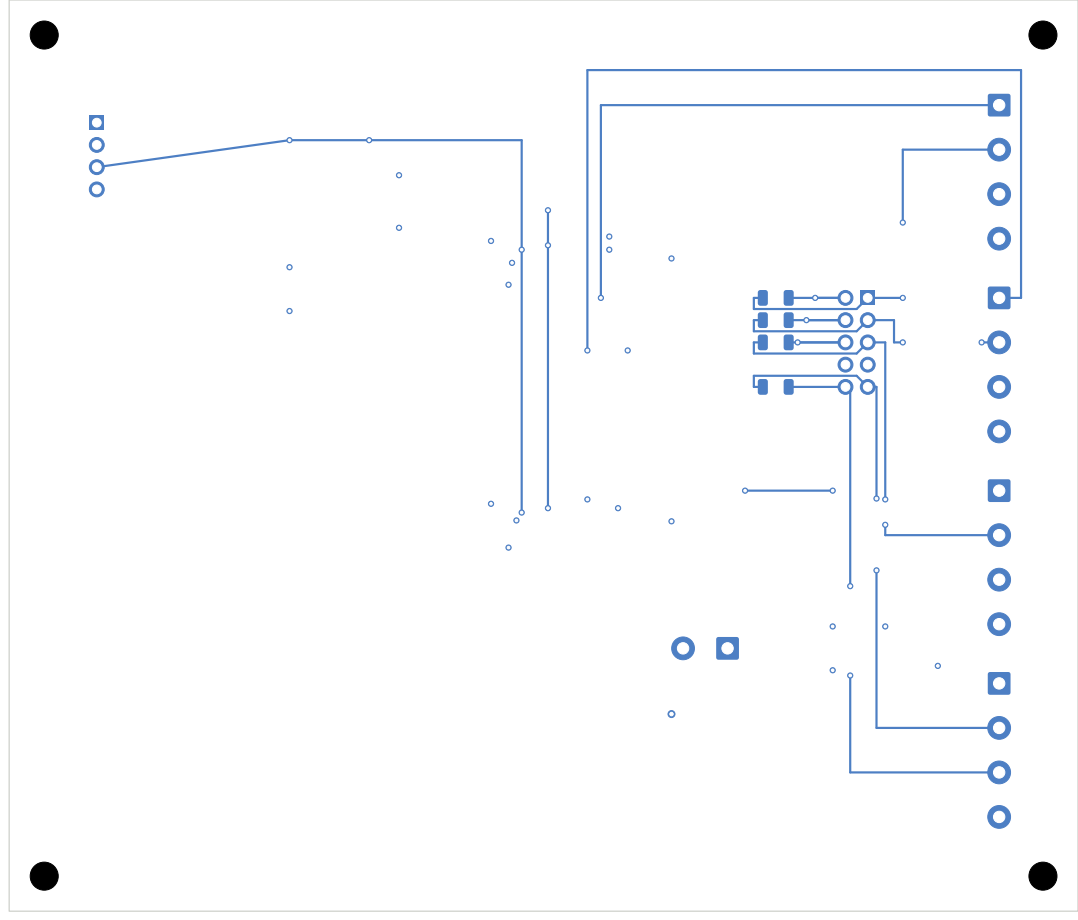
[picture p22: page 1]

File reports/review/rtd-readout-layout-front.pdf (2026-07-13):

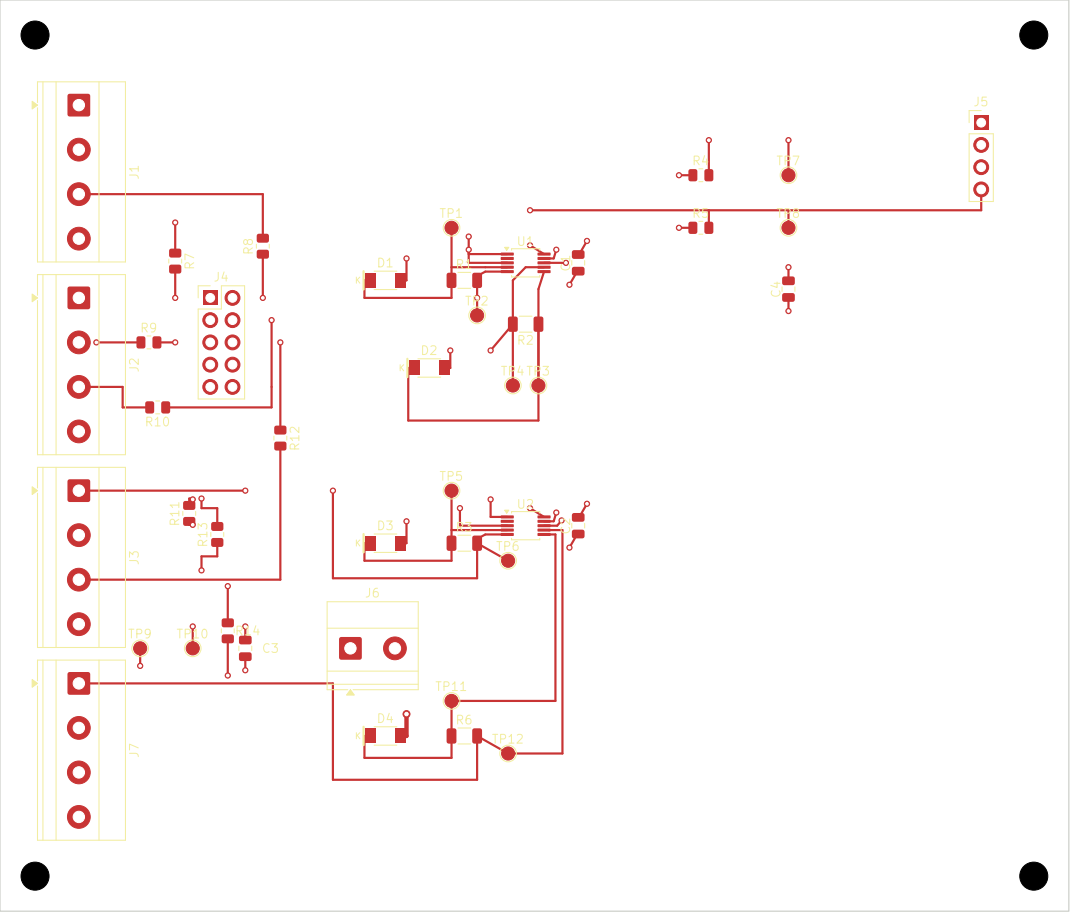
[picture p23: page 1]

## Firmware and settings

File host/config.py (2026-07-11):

"""Board / acquisition configuration for the dual-ADC RTD readout board.

Single source of truth for the electrical parameters and the two converter maps:
the T7 differential pairs that read **V_RTD**, and the ADS1115 chip/input
assignment that reads **V_ref** over I²C. Everything traces back to
``docs/board_spec.md``; the defaults reproduce the resolved design point
(board_spec.md "Resolved inputs", Session 002):

    Pt100, 3 channels, ~100 µA CRD, R_ref ≈ 1.00 kΩ,
    T7 range ±0.1 V, ADS1115 PGA range ±0.256 V,
    2 ADS1115 at 0x48 / 0x49 (1 chip per 2 channels), 3 V_ref reads (1 spare).

The whole module is parameterized: switching to Pt1000 or changing the channel
count (up to 7) is a one-call change (``make_config`` / ``preset``), not a
rewrite. Counts derive from the channel count exactly as the spec describes
(``ceil(n/2)`` ADS1115 chips), so the tooling scales with the board.
"""

from __future__ import annotations

import math
from dataclasses import dataclass, field
from typing import Dict, List, Tuple

# T7 register code selecting single-ended (negative terminal = internal GND).
T7_GND_NEG_CH = 199

# Quantity keys used throughout the acquisition + bench code.
Q_VREF = "vref"   # voltage across R_ref, read by an ADS1115 (I²C)
Q_VRTD = "vrtd"   # voltage across the RTD (Kelvin), read by the T7 diff pair

# ADS1115 differential MUX selections actually wired on this board
# (board_spec.md "Components / ADS1115": AIN0-AIN1 and AIN2-AIN3 per chip).
# These are the raw 3-bit MUX field values; the driver packs them into the
# config register. Kept here because they are a board-wiring fact, not protocol.
ADS_MUX_0_1 = 0b000   # IN+ = AIN0, IN- = AIN1
ADS_MUX_2_3 = 0b011   # IN+ = AIN2, IN- = AIN3

# Selectable ADS1115 I²C addresses via the ADDR strap (board_spec.md).
ADS_ADDRESSES = (0x48, 0x49, 0x4A, 0x4B)
ADS_BASE_ADDRESS = 0x48


@dataclass(frozen=True)
class T7Pin:
    """One T7 differential analog read for a channel's V_RTD (Kelvin sense pair)."""

    channel: int
    pos: int            # positive AIN index
    neg: int            # negative AIN index (even/odd diff pairing)

    @property
    def read_name(self) -> str:
        return f"AIN{self.pos}"


@dataclass(frozen=True)
class ADSInput:
    """One ADS1115 differential read for a channel's V_ref."""

    channel: int
    address: int        # I²C 7-bit address (0x48..0x4B)
    mux: int            # 3-bit MUX field (ADS_MUX_0_1 / ADS_MUX_2_3)

    @property
    def pair_label(self) -> str:
        return "AIN0-1" if self.mux == ADS_MUX_0_1 else "AIN2-3"

    @property
    def addr_hex(self) -> str:
        return f"0x{self.address:02X}"


@dataclass(frozen=True)
class BoardConfig:
    """Complete electrical + acquisition configuration for one bench run."""

    rtd_type: str                  # "Pt100" | "Pt1000"
    r0_ohms: float                 # RTD nominal at 0 degC
    n_channels: int
    excitation_current_a: float    # per-channel CRD current (nominal; measured live)
    r_ref_ohms: float              # reference resistor (nominal; value absorbed into C)
    # --- T7 side (V_RTD) ---
    t7_range_v: float              # T7 AIN ± range
    t7_resolution_index: int       # T7 RESOLUTION_INDEX (0 = device default)
    t7_settling_us: float          # T7 AIN settling time (guards mux settling)
    # --- ADS1115 side (V_ref) ---
    ads_range_v: float             # ADS1115 PGA full-scale (±), e.g. 0.256 V
    ads_data_rate_sps: int         # ADS1115 conversion data rate
    ads_navg: int                  # ADS conversions averaged per V_ref read
    # --- I²C transport pins on the T7 (real backend only) ---
    i2c_sda_dion: int = 0          # FIO/EIO line number for SDA
    i2c_scl_dion: int = 1          # FIO/EIO line number for SCL
    # --- stability metadata (not precision; cross-cal absorbs value) ---
    r_ref_tempco_ppm_per_c: float = 10.0   # <=10 ppm/degC target
    temp_range_c: Tuple[float, float] = (-50.0, 150.0)
    # --- maps (built by the factory) ---
    t7_map: Dict[int, T7Pin] = field(default_factory=dict)
    ads_map: Dict[int, ADSInput] = field(default_factory=dict)

    # ---- derived expected values (board_spec.md "Components") ------------
    @property
    def channels(self) -> List[int]:
        return list(range(self.n_channels))

    @property
    def v_ref_nominal(self) -> float:
        return self.excitation_current_a * self.r_ref_ohms

    def v_rtd_nominal(self, r_rtd: float) -> float:
        return self.excitation_current_a * r_rtd

    @property
    def n_ads_chips(self) -> int:
        """1 ADS1115 per 2 channels (2 differential inputs each)."""
        return math.ceil(self.n_channels / 2)

    @property
    def ads_addresses(self) -> List[int]:
        """Distinct ADS1115 addresses in use, in scan order."""
        seen: List[int] = []
        for ch in self.channels:
            a = self.ads_map[ch].address
            if a not in seen:
                seen.append(a)
        return seen

    # ---- read helpers ----------------------------------------------------
    def t7_read_names(self) -> List[str]:
        return [self.t7_map[ch].read_name for ch in self.channels]

    def t7_reverse_lookup(self) -> Dict[str, int]:
        return {self.t7_map[ch].read_name: ch for ch in self.channels}

    def summary(self) -> str:
        return (
            f"{self.rtd_type} R0={self.r0_ohms:g}ohm  {self.n_channels}ch  "
            f"I~{self.excitation_current_a * 1e6:g}uA  R_ref~{self.r_ref_ohms:g}ohm  "
            f"T7=±{self.t7_range_v:g}V/res{self.t7_resolution_index}/set{self.t7_settling_us:g}us  "
            f"ADS=±{self.ads_range_v:g}V/{self.ads_data_rate_sps}SPS/navg{self.ads_navg}  "
            f"{self.n_ads_chips}chip@{','.join(f'0x{a:02X}' for a in self.ads_addresses)}"
        )


# --------------------------------------------------------------------------
# Map builders
# --------------------------------------------------------------------------
def build_t7_map(n_channels: int) -> Dict[int, T7Pin]:
    """Channel ch -> T7 differential pair (AIN{2ch} / AIN{2ch+1}).

    The T7 Pro has 7 differential pairs; up to 7 RTD channels map onto them
    one-to-one (board_spec.md: the 7 pairs are committed to V_RTD).
    """
    if not 1 <= n_channels <= 7:
        raise ValueError("n_channels must be 1..7 (T7 has 7 differential pairs)")
    return {ch: T7Pin(ch, pos=2 * ch, neg=2 * ch + 1) for ch in range(n_channels)}
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

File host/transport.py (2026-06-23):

"""Transport: the single device that does both jobs, plus a hardware-free mock.

On the bench one LabJack T7 Pro carries the whole acquisition: it reads V_RTD on
its analog differential pairs **and** drives the ADS1115 I²C bus on its digital
lines (board_spec.md "Board as the hub"). So the transport exposes two surfaces
behind one connection:

  * analog  -- ``read_analog`` / ``write_register`` (LJM eReadNames/eWriteNames)
  * I²C     -- ``i2c_xfer`` (LJM I2C register block on the same handle)

The drivers (``t7_rtd``, ``ads1115``) talk only to this interface, never to
``labjack.ljm`` directly, so every stage runs with no hardware (``MockTransport``)
and the real path is a drop-in swap. The mock simulates the physical unit cell
*and* models the ADS1115 at the I²C-register level, so the real ADS1115 register
packing/unpacking in ``ads1115.py`` is exercised in dry runs -- not bypassed.
"""

from __future__ import annotations

from abc import ABC, abstractmethod
from dataclasses import dataclass
from typing import Dict, List, Optional, Sequence, Tuple

import numpy as np

from host.config import (
    ADS_MUX_2_3,
    BoardConfig,
    DEFAULT_CONFIG,
)
from host.rtd import resistance_from_temp

# ADS1115 register pointers and PGA full-scale table (datasheet Table; also used
# by the real driver). Kept here too so the mock can model the chip faithfully.
ADS_REG_CONVERSION = 0x00
ADS_REG_CONFIG = 0x01
ADS_PGA_FS_VOLTS = {
    0b000: 6.144,
    0b001: 4.096,
    0b010: 2.048,
    0b011: 1.024,
    0b100: 0.512,
    0b101: 0.256,
    0b110: 0.256,
    0b111: 0.256,
}


def pga_lsb_volts(pga_field: int) -> float:
    """Volts per LSB for an ADS1115 PGA field (16-bit, ±FS over 2^15)."""
    return ADS_PGA_FS_VOLTS[pga_field] / 32768.0


# ==========================================================================
# Abstract transport
# ==========================================================================
class Transport(ABC):
    """Minimal device interface: analog reads + register writes + I²C xfers."""

    @abstractmethod
    def read_analog(self, names: Sequence[str]) -> List[float]: ...

    @abstractmethod
    def write_register(self, names: Sequence[str], values: Sequence[float]) -> None: ...

    @abstractmethod
    def i2c_config(self, sda_dion: int, scl_dion: int) -> None: ...

    @abstractmethod
    def i2c_xfer(self, address: int, tx: bytes, num_rx: int) -> Tuple[bytes, bool]:
        """Write ``tx`` then read ``num_rx`` bytes from ``address``.

        Returns (rx_bytes, ack) where ``ack`` is True if the slave acknowledged
        (used by the bus scan to detect present chips).
        """

    @abstractmethod
    def info(self) -> Dict[str, object]: ...

    @abstractmethod
    def close(self) -> None: ...

    def __enter__(self) -> "Transport":
        return self

    def __exit__(self, exc_type, exc, tb) -> None:
        self.close()


def get_transport(mock: bool = True, identifier: str = "ANY", **mock_kwargs) -> Transport:
    """Return a real (LJM) or mock transport. ``mock=True`` is the dry-run default."""
    if mock:
        return MockTransport(**mock_kwargs)
    return LJMTransport(identifier=identifier)


# ==========================================================================
# Real LabJack T7 Pro transport (LJM)
# ==========================================================================
class LJMTransport(Transport):
    """T7 Pro over LJM: eReadNames for V_RTD, the I2C register block for V_ref.

    ``labjack-ljm`` and the LJM runtime are imported lazily so the mock path
    needs neither. Untested against silicon in this repo -- the bench operator
    validates it in Stage 1; the mock mirrors the same call surface.
    """

    def __init__(self, identifier: str = "ANY", device: str = "T7", connection: str = "ANY"):
        try:
            from labjack import ljm  # noqa: WPS433 (lazy, optional dependency)
        except ImportError as exc:  # pragma: no cover - depends on host install
            raise RuntimeError(
                "labjack-ljm is not installed. Install the LJM runtime and "
                "`pip install labjack-ljm`, or run with the mock transport."
            ) from exc
        self._ljm = ljm
        self._handle = ljm.openS(device, connection, identifier)
        self._i2c_ready = False

    # ---- analog ----------------------------------------------------------
    def read_analog(self, names: Sequence[str]) -> List[float]:
        vals = self._ljm.eReadNames(self._handle, len(names), list(names))
        return [float(v) for v in vals]

    def write_register(self, names: Sequence[str], values: Sequence[float]) -> None:
        self._ljm.eWriteNames(self._handle, len(names), list(names),
                              [float(v) for v in values])

    # ---- I²C -------------------------------------------------------------
    def i2c_config(self, sda_dion: int, scl_dion: int) -> None:
        self._ljm.eWriteName(self._handle, "I2C_SDA_DIONUM", float(sda_dion))
        self._ljm.eWriteName(self._handle, "I2C_SCL_DIONUM", float(scl_dion))
        # Default options; throttle 0 -> ~100 kHz. ADS1115 supports up to 400 kHz.
        self._ljm.eWriteName(self._handle, "I2C_OPTIONS", 0.0)
        self._ljm.eWriteName(self._handle, "I2C_SPEED_THROTTLE", 0.0)
        self._i2c_ready = True

    def i2c_xfer(self, address: int, tx: bytes, num_rx: int) -> Tuple[bytes, bool]:
        if not self._i2c_ready:
            raise RuntimeError("i2c_config() must be called before i2c_xfer()")
        ljm, h = self._ljm, self._handle
        ljm.eWriteName(h, "I2C_SLAVE_ADDRESS", float(address))
        ljm.eWriteName(h, "I2C_NUM_BYTES_TX", float(len(tx)))
        ljm.eWriteName(h, "I2C_NUM_BYTES_RX", float(num_rx))
        if tx:
            ljm.eWriteNameByteArray(h, "I2C_DATA_TX", len(tx), list(tx))
        ljm.eWriteName(h, "I2C_GO", 1.0)
        acks = int(ljm.eReadName(h, "I2C_ACKS"))
        rx = b""
        if num_rx:
            data = ljm.eReadNameByteArray(h, "I2C_DATA_RX", num_rx)
            rx = bytes(int(b) & 0xFF for b in data)
        return rx, acks > 0

    def info(self) -> Dict[str, object]:
        name = self._ljm.eReadNameString(self._handle, "DEVICE_NAME_DEFAULT")
        serial = int(self._ljm.eReadName(self._handle, "SERIAL_NUMBER"))
        fw = float(self._ljm.eReadName(self._handle, "FIRMWARE_VERSION"))
        return {"backend": "ljm", "device_name": name, "serial": serial, "firmware": fw}

    def close(self) -> None:
        try:
            self._ljm.close(self._handle)
        except Exception:  # pragma: no cover - best-effort close
            pass
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

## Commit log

2026-06-22 Session 001: bootstrap repo skeleton, relocate docs, vendor old REF200 project
    - Create directory tree per docs/DIRECTORY_MANAGEMENT.md (.gitkeep in empty dirs)
    - Move 7 process docs + board_spec.md from root into docs/
    - Move 7 TRACK_*.md briefs from root into docs/tasks/
    - Add .gitignore (base name rtd-readout); fab/ ignored, reports/ committed
    - Vendor old REF200 project under references/ as read-only reference; nested
    history preserved on disk as .git.disabled (gitignored), not an embedded repo
    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
    [example_series_chain.csv]
2026-06-22 Session 002: resolve open inputs (Pt100, 3 channels) and lock derived counts
    - board_spec.md: Open inputs -> Resolved inputs. RTD = Pt100 (T7 +/-0.1 V);
    3 RTD channels -> 3 CRD/R_ref cells, 2 ADS1115 (ADDR 0x48/0x49, 4 reads/1 spare),
    3 RTD 4-wire connectors, 3 of 7 T7 Sense+/- pairs used.
    - Unblocks Track E (schematic) once Track A (libraries) merges.
2026-06-22 trackA: project-local symbol + footprint libs (10 parts); lib tables local-only
    Symbols (libraries/symbols/rtd-readout.kicad_sym, all fully fielded):
    CRD_1N5283, R_ref (tempco<=10ppm/C), R, C, ADS1115, Conn_RTD_4W,
    Conn_T7_Analog, Conn_T7_I2C, Conn_Power, TestPoint.
    Footprints (libraries/footprints/rtd-readout.pretty): 10 IPC-vetted parts
    copied from KiCad 10.0.3 std libs, verified vs datasheet land patterns.
    sym-/fp-lib-table point ONLY at ${KIPRJMOD}/../libraries (no global refs).
    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
2026-06-22 trackD: gate scripts + run_gates entry + README; gates pass vacuously (no design files yet)
    POSIX sh wrappers for the canonical kicad-cli gates (ERC, DRC, BOM w/ Tempco,
    netlist, fab drop) + single scripts/run_gates entry that degrades gracefully
    (exit 0, "nothing to check") until the schematic/PCB land. kicad-cli auto-
    discovery (PATH or Windows install), pinned KiCad 10.0.3. Opt-in pre-commit
    hook. README expanded; scripts/.gitattributes forces LF; exec bits set.
    Validation: run_gates exit 0 (no hardware/*.kicad_*); wrappers exit 2 on
    missing input; ERC+BOM command lines smoke-tested on a KiCad 10.0.3 demo
    (ERC 0/0, BOM header carries Tempco).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
2026-06-22 Track C: host/ acquisition library + test/ staged bench procedures
    Dual-ADC RTD readout: T7 reads V_RTD on its diff pairs, ADS1115 reads V_ref over
    I2C on the T7's digital lines; live ratiometric R = C*(V_RTD/V_ref) with a
    per-channel cross-cal constant C = R_known*(V_ref/V_RTD).
    host/ - config, transport (LJM + I2C-register-level mock), t7_rtd + ads1115
    drivers, time-aligned dual read (acquire), cross-cal math, C persistence.
    test/ - bench harness (datalog/stats/report/baseline_gen/common) + Stage 0-8
    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
    [example_series_chain.csv]
2026-06-22 sim: full ngspice harness + accuracy/noise budget; all 7 tests PASS
    Track B Wave-0. Models (CRD, R_ref, two-ADC gain blocks, unit cell), 7 decks
    covering TESTING_PLAN Part-1, and a single-entry python runner (run_all.py)
    that runs every deck headless, analyses, and writes one report + plot per test.
    Validation (reports/sim/*.md), all vs TESTING_PLAN criteria:
    - test1 DC/compliance: PASS min V_CRD 4.26 V >> V_L 1.05 V (rail 4.5 V)
    - test2 ratio+xcal: PASS R_calc invariant to +/-10% CRD/R_ref (err ~7e-9)
    - test3 Monte-Carlo: PASS sigma 0.0376 C (RSS 0.0380), tempco-dominated
    - test4 R_ref sizing: PASS V_ref 86% of ADS FS at +10% CRD, 14.8 bits
    - test5 transient: PASS RC settles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
2026-06-22 trackE: capture full hierarchical schematic (3 ch); ERC clean (0 err/0 warn)
    Root + 3 unit_cell + acquisition + power_io sheets, parts from project-local
    rtd-readout lib. CRD->R_ref->RTD loop per channel; V_ref differential to 2x
    ADS1115 (0x48/0x49, 1 spare); Sense pairs to T7 analog; I2C to T7 digital.
    BOM counts match board_spec (CRD=3, R_ref=3, ADS=2, pullups=2, RTD conn=3,
    TP=10). Netlist exported to sim/netlists/ for Track B.
    [acquisition.kicad_sch, power_io.kicad_sch, rtd-readout.kicad_sch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]
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2026-06-22 trackA: log post-review nits (D_MELF fab-glyph polarity note; MSOP/VSSOP naming)
    Review passed; both cosmetic. Document that D_MELF pad1=cathode is consistent across
    pads/silk/fab/symbol so the fab glyph is not mistakenly 'fixed'; note MSOP-10 == VSSOP/DGS
    land (MO-187 var BA), KiCad canonical name kept intentionally.
2026-06-22 trackE: record accepted 3-sheet deviation + clean loose reports artifacts
    Integration-review housekeeping (no schematic logic change):
    - Mark the three-sheet unit_cell structure as an ACCEPTED deviation in
    docs/sessions/trackE.md, with the consequence noted (a unit-cell change must
    be applied to all three sheets by hand).
    - Add a one-line note in root rtd-readout.kicad_sch (title-block comment 2 +
    on-canvas text) so the next reader isn't surprised.
    - Remove loose untracked reports/ gate artifacts so the tree is clean for merge.
    ERC re-confirmed 0 errors / 0 warnings after the root-sheet edit.
    [rtd-readout.kicad_sch]
2026-06-22 trackD: review fixes — netlist --format spice for Track B; doc nits
    export_netlist now emits SPICE (was kicadsexpr default): Track B's ngspice decks
    .include sim/netlists/rtd-readout.net (sim/README.md Wave-3 hook), so they need a
    flat SPICE deck. Verified against a KiCad 10.0.3 demo. Plus two nits: note the
    count_severity pretty-JSON assumption (exit code is authoritative), and a caveat
    that the pre-commit hook gates the working tree, not the staged index.
2026-06-22 Track C: review follow-up — ADS1115 robustness fixes
    Apply the three minor items from the passing review:
    - ads1115._read_once raises IOError on conversion timeout instead of reading
    stale data when the OS-bit poll falls through (stuck/NACKing chip).
    - stage8_crd_noise guards each V_ref read so an unresponsive ADS fails its gate
    rather than crashing the stage.
    - Optional[int] for None-defaulted n_avg/ads_navg in ads1115/acquire.
    Add test_ads_conversion_timeout_raises; dry-run self-test 12/12 (pytest 12
    passed); pyflakes + flake8 F/E9 clean.
    [acquire.py, ads1115.py]
2026-06-22 sim: integration-review fixes (test7 re-scope, test6 conditional); all 7 still PASS
    Addresses the trackB integration review. Stays in sim/ and reports/sim/.
    [MAJOR] test7 measured nothing: the victim ratio V_RTD/V_ref cancels the channel
    current algebraically, so every test7_rg_*.dat was bit-identical (cancellation by
    construction, not a numerical floor). Re-scoped via reviewer option (a): added a
    finite-CMRR term to meas.inc (cmrr subckt param, default 1e12 -> tests 1-6 untouched);
    test7 now sets ADC CMRR (T7 90 dB, ADS 105 dB) and sweeps the aggressor CURRENT over
    its +/-10% CRD spread (what actually moves the shared-return common mode). Coupling is
    now real and linear in R_gn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
2026-06-23 integration: close out Wave-0 — Tracks A–E merged; ERC 0/0 on merged tree
    Merged B, C, D, E into integration (no-ff, zero conflicts). Re-gated via
    scripts/run_gates: ERC 0 errors / 0 warnings, DRC skipped (no PCB). Global
    SESSION_LOG Session 003 records per-track summaries, the accepted 3-sheet
    deviation, and the open Track B test6/test7 wording items.
2026-06-23 docs: mark Track B test6/test7 items resolved (verified in merged tree)
2026-06-23 trackE: wire-up pass -- drawn wires + power symbols (netlist unchanged)
    Convert the label-based capture to a conventionally drawn schematic: unit cells
    as a drawn series current-loop (+5V/GND power symbols, CRD->R_ref->RTD, tapped
    TOP/MID to TPs+labels); acquisition/power_io pins stub to power symbols/labels;
    cross-sheet signals stay labelled. Fixed a y-down rotation bug (CRD anode/cathode
    swap) by rotating the CRD 90 not 270.
    ERC 0 errors / 0 warnings. Netlist node-for-node IDENTICAL to the pre-wiring
    verified netlist (21 nets, diff empty); sim/netlists refreshed.
    [acquisition.kicad_sch, power_io.kicad_sch, rtd-readout.kicad_sch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]
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2026-06-24 trackF: lay out + route 4-layer board; DRC clean (0 err/0 unconnected)
    Full scripted layout via pcbnew API (4-layer JLCPCB, size-to-fit). R_ref at each
    ADS (short V_ref), J4 by the RTD connectors (short sense), analog-left/digital-right
    partition with ADS straddle. In1 = split GND plane (AGND/DGND + single-point tie =
    star ground); In2 = split +5V/VS planes. Netclasses SENSE/POWER/I2C/Default.
    Validation: DRC 0/0 (--severity-error, exit 0; all-severity also 0/0); netlist match
    exact (30/30 comps, 21/21 nets pad-for-pad); zones filled. Deviation logged: sense-line
    RC filter not placed (not in frozen E schematic -> needs schematic ECO).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
    [rtd-readout.kicad_pcb]
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2026-06-25 integration: log Session 004 — merge Track E wire-up + Track F layout
    ERC 0/0, DRC 0 violations / 0 unconnected on merged tree. 47 schematic-parity
    issues are pre-existing in trackF (mechanical footprints w/o symbol + un-synced
    metadata fields), not introduced by the merge. Repo-move worktree links repaired.
2026-06-25 trackG: rev-A fab package + closeout (fab generated, SPICE re-run all-pass)
    Gerbers/drill/pos/STEP/BOM cut to fab/ (gitignored; tag fab-rev-A). ERC 0/0,
    DRC 0/0 at rev-A. BOM cross-checks board_spec (D=3,R=5,U=2,C=4,J=6,TP=10).
    4-layer/1.6mm, standard-fab rules. SPICE harness re-run vs real netlist: all 7
    PASS, byte-identical to Track B. Review artifacts in reports/review/.
    Bench verification (Part 2) deferred to physical board.
2026-06-25 docs: add USER_MANUAL.md — single read to understand + assess the board
    Covers circuit rationale (ratiometric, two-ADC cross-cal), as-built config,
    verified BOM, layout/stackup, interfaces, verification evidence (ERC 0/0,
    DRC 0/0, SPICE 7/7 with reproduce commands), ordering/assembly, calibration,
    operation, and the pending bench plan. README points to it.
2026-07-09 rev-B: real Digi-Key parts + layout review (copper unchanged)
    Independent layout review + adversarial verify: 4-layer split planes, single-
    point analog/digital GND tie, Kelvin intact -> fabricable (yes-with-fixes).
    Real Digi-Key MPNs on the whole BOM; fixed RTD conn P/N (1729160 6-pos ->
    1729144 4-pos) and R_ref tempco (25ppm -> Vishay TNPU1206 <=10ppm per spec).
    ERC 0/0, DRC 0/0. Open decision: sense-line RC filter (see USER_MANUAL 8.5).
    [acquisition.kicad_sch, power_io.kicad_sch, unit_cell_ch1.kicad_sch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]
2026-07-11 schematic: restructure for auditability (page1 = ch1+acquisition+power, drawn wires)
    Page 1 merges unit_cell_ch1 + acquisition + power_io with 28 drawn join wires
    (CH1 taps -> U1 AIN0/1, Kelvin sense pairs -> J4, I2C bus U1->U2->J5); pages
    2-3 = CH2/CH3 cells. Blocks rigidly translated, labels kept: netlist verified
    node-for-node IDENTICAL (21 nets, 80 nodes) vs pre-restructure; ERC 0/0; DRC
    parity unchanged (47 cosmetic). Verified by 5-agent workflow (independent
    netlist oracle, gates, visual audit, BOM byte-identical, adversarial trace);
    visual-audit findings fixed (label flips reverted, power-text normalized,
    values repositioned, J4 pin names hidden, pages 2-3 title blocks). PCB
    untouched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
    [acquisition.kicad_sch, power_io.kicad_sch, rtd-readout.kicad_sch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]
2026-07-11 rev-C: 4th channel — CH4 on U2's spare AIN2/3, J4 2x5, board grown south
    board_spec 3->4ch. Schematic: page 4 (D4/R6/J7/TP11/TP12), U2 AIN2/3 wired,
    Conn_T7_Analog 2x5 (CH4 sense on pins 9/10, AGND kept on 7/8); netlist delta
    verified exactly the CH4 additions (21->23 nets). Library: 2x05 footprint +
    symbol updated (embedded/library kept identical). Layout via pcbnew: board
    122x82->122x104, holes moved, planes extended+refilled, CH4 placed/routed,
    CH2_SENSE- rerouted off the new J4 row, one VS via relocated. ERC 0/0 (all
    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
    [rtd-readout.kicad_pcb, rtd-readout.kicad_sch, unit_cell_ch4.kicad_sch]
2026-07-11 rev-D: sense-line RC filters fitted (1k per leg + 0.1uF diff at J4, x4 ch)
    Schematic: R7-R14 inline in CHn_SENSE+/- + C5-C8 differential; filtered nets
    CHn_T7+/- labeled; netlist delta = exactly the filter insertion (23->31 nets,
    oracle mutation-tested). Layout: Rs inline in existing legs (F-inline or
    via-sandwich), caps on B.Cu across J4 pin pairs (courtyard-less variant);
    ERC 0/0, DRC 0/0/0 (parity 84 metadata-only, 0 net conflicts); adversarial
    copper review: all 8 filters genuinely in series, min clearance 0.315mm,
    GND tie untouched. SPICE 7/7 - test5 now models fitted hardware. Fleet
    visual findings fixed (text de-stacking, label moves, silk offsets, zero-
    length residue). Closes the Se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
    [rtd-readout.kicad_pcb, rtd-readout.kicad_sch]
2026-07-11 sim: official rev-D SPICE run (7/7 PASS; test5 now models fitted filters)
    Monte-Carlo report refreshed (new random draws, statistics unchanged:
    sigma ~0.038 C, tempco-dominated). test5 deck RF=1k/CF=0.1u == R7-R14/C5-C8.
2026-07-11 docs: Session 010 handoff — state, environment, and next steps for a new machine
    SESSION_LOG handoff entry: exact repo/tag state (rev-D complete, nothing open
    in the design), environment setup (KiCad 10.0.x, ngspice via conda +
    NGSPICE_BIN, gates/fab commands), remaining physical-world work (order at
    fab-rev-D after confirming cart codes; bench TESTING_PLAN Part 2). BOM_REVIEW
    source-rev nits fixed.
2026-07-11 rev-E: DFM/availability respin - CRD J500 TO-92, 0805 caps, R_ref 820R
    Hand-assembly + live-Digi-Key-verified changes (all adversarially fact-checked):
    - D1-D4: CDLL5283 MELF (unbuyable, 0 stock/40wk MOQ) -> LIS J500 TO-92 2L;
    new mirrored footprint TO-92-2_CRD-J500 (pad1=K at flat-to-silk insertion,
    0.8mm drill), 8 F.Cu stubs bridge old MELF trace ends to the THT pads.
    - C1-C8: 0603 -> 0805 (Samsung CL21B104KBCNNNC / CL21A106KACLRNC; old Murata
    parts obsolete/backordered). C5-C8 keep the back-side across-J4 scheme.
    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
    [rtd-readout.kicad_pcb, rtd-readout.kicad_sch, unit_cell_ch2.kicad_sch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]
2026-07-11 rev-F: cryostat/stability respin - 100uA S-101T CRD, C0G sense path, 2ppm R_ref
    Sensors are in a vacuum cryostat down to ~100 K; excitation lowered to cut
    self-heating ~6x (0.3-1.6 uW nominal), measurement path upgraded to
    precision-grade passives. All parts live-verified on Digi-Key with
    adversarial fact-checks:
    - D1-D4: LIS J500 TO-92 -> SEMITEC S-101T (100uA typ, band 0.05-0.21mA,
    SMD flat 2-lead); custom footprint from SEMITEC's recommended land
    pattern (1.2x1.6mm pads, 3.4mm centers, cathode-band marking).
    - R_ref: 820R 10ppm -> 1.00k +/-0.05% +/-2ppm/C (Vishay TNPU12061K00AWEN00);
    V_ref 100mV nom, 210mV = 82% FS at band max. Reference is no longer the
    drift limiter (by design).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
    [rtd-readout.kicad_pcb, rtd-readout.kicad_sch, unit_cell_ch2.kicad_sch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]
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2026-07-13 rev-G: enclosure integration - 100x159.5 board, Hammond 1455N, RJ45/PT/KK I/O
    Board resized to slide into a Hammond 1455N1601 extrusion (machinable end
    panels, connectors proud/flush through cutouts). All parts live-verified
    with adversarial fact-checks:
    - RTD inputs: 4x Phoenix PT 1,5/5-3,5-H push-in blocks (pin 5 = cable
    shield to AGND); kept terminal blocks over RJ45 for bare cryo cables.
    - T7 analog: Amphenol RJHSE-5380 shielded RA RJ45, T568 pair mapping
    (CH1=1/2, CH2=3/6, CH3=4/5, CH4=7/8), shield+chassis bond at the jack.
    - T7 I2C: Molex KK 254 friction-lock header; pin numbers reversed (1<->4,
    2<->3) to make the fan planar - pigtail map in PANELS_AND_PINOUTS.md.
    - Routing: via-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
    [panel-daq.dxf, panel-sensor.dxf, rtd-readout.kicad_pcb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]
2026-07-14 order: drag-and-drop DigiKey CSV for rev-G (3 boards + spares)
    [digikey-order-revG.csv]
2026-07-14 order: DigiKey CSV re-scoped to 1 board + 20% spares
    [digikey-order-revG.csv]
2026-07-14 rev-G.1: J5 -> Molex PicoBlade 53048-0410 (no-crimp pre-made pigtail 2181120404)
    Lucas found the 218112 PicoBlade pigtail family - swapped the I2C header
    so the pre-made 425mm assembly plugs straight in (zero crimping). Pin
    order (1=SCL..4=VS) unchanged; I2C re-routed as 4 parallel diagonals to
    the new 1.25mm pads. Panel DXF, PANELS_AND_PINOUTS, BOM_REVIEW, order
    CSV updated; DKRed zip regenerated.
    Gates: ERC 0/0, DRC 0 violations / 0 unconnected.
    [digikey-order-revG.csv, panel-daq.dxf, rtd-readout.kicad_pcb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]
